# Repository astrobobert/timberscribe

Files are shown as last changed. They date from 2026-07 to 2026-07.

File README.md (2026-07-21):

# TimberScribe — Laser Print Head Server

**TimberScribe** is the scribing side of the **Timber Frame Suite** — an open-source
CAD/CAM system for traditional timber framers. A self-propelled laser print head
rides the timber and burns the joinery layout — mortise outlines, cut lines, bore
centers, labels — directly onto the wood. The joints themselves are still cut by
hand with traditional tools: the laser replaces tape-measure layout, not
craftsmanship.

This repository is the web server that drives the print head. It runs on a
shop server — a plugged-in Raspberry Pi or any laptop on the same network as
the sled — accepts `.tsj` job files from the framer's phone, shows a face
preview dialog, and streams g-code over WiFi to the sled's GRBL controller
(an MKS DLC32 V2.2 running
[FluidNC](https://github.com/bdring/FluidNC); nothing rides the sled but the
controller itself). It also exports `.gcode` files for running from the
controller's SD card when there's no server around — see "Two ways to run a
burn" below.

`.tsj` jobs are produced by the [TimberDraw](https://github.com/astrobobert/timberdraw)
AutoCAD plugin's scribe export (`TScribe` / `TScribeAll`) — one file per timber face,
with profile linework, cut-to-length lines, depth/bevel labels, and peg bores.
The file format is specified in [TSJ_SPEC.md](TSJ_SPEC.md); `app/tsj_parser.py`
is its reference validator. Building the sled itself — printed parts, BOM,
assembly — is covered in [HARDWARE.md](HARDWARE.md).

---

## Two ways to run a burn

**Shop mode (streamed):** the sled joins the shop WiFi (FluidNC station
mode), this server runs on a machine on the same network — a plugged-in
Raspberry Pi (below) or any laptop — and your phone drives the web UI:
upload, preview, adjust, print. G-code streams live to the controller
at `fluidnc.local` (TCP 23), with per-entity status on the phone.

**Field mode (SD card):** out of router range the sled automatically
falls back to broadcasting its own hotspot, and no server is needed at
all. Export a `.gcode` file ahead of time — the **Export .gcode**
button on the face page, or `python export_gcode.py <file.tsj>` — get
it onto your phone, join the sled's hotspot, upload the file to the
controller's SD card through the board's own web page, and run it from
there. A card-run burn doesn't need WiFi once started. (The card:
4–16 GB, FAT32.)

Firmware flashing, WiFi setup, and homing are covered in
[HARDWARE.md](HARDWARE.md) §4. A bench fallback over USB serial also
exists: set `GRBL_TRANSPORT = "serial"` and `SERIAL_PORT` in
`config.py` and plug the DLC32 into USB.

## Setup (any server machine)

```bash
cd TimberScribe
python -m venv .venv
source .venv/bin/activate      # Windows: .venv\Scripts\activate
pip install -r requirements.txt
python run.py
```

Open on a phone on the same network:
```
http://<server-ip>:5000
```

## Shop server on a Raspberry Pi

A Pi plugged in on the shop network makes the server an appliance — no
laptop in the workflow. One-time setup on the Pi:

```bash
git clone https://github.com/astrobobert/timberscribe.git ~/TimberScribe
cd ~/TimberScribe
python -m venv .venv
.venv/bin/pip install -r requirements.txt

# Start on every boot:
sed "s|USER|$(whoami)|g" deploy/timberscribe.service | \
  sudo tee /etc/systemd/system/timberscribe.service
sudo systemctl enable --now timberscribe
```

Then browse to `http://<pi-ip>:5000` from the phone — give the Pi a
reserved address in the router and bookmark it. `fluidnc.local`
resolution works out of the box on Raspberry Pi OS (avahi). Logs:
`journalctl -u timberscribe -f`.

---

## Development

Run with auto-reload:
```bash
flask --app run:app run --debug --host 0.0.0.0 --port 5000
```

The hardware layer (`hardware/executor.py`) gracefully falls back to a
simulation mode when the GRBL controller is unreachable (no sled hotspot,
no serial port), so the full web UI works on a dev machine without the
sled. Simulated completions are labeled as such in the job status.

---

## Project layout

```
TimberScribe/
├── app/
│   ├── __init__.py       Flask app factory
│   ├── routes.py         HTTP endpoints
│   ├── job_store.py      SQLite job queue
│   ├── tsj_parser.py     .tsj file validation and parsing
│   └── executor.py       Background print thread
├── hardware/
│   ├── __init__.py
│   ├── executor.py       GRBL g-code sender (WiFi / USB serial)
│   └── fluidnc/
│       ├── config.yaml   The controller's FluidNC config (source of truth)
│       └── upload_config.py  Bench tool: push config.yaml to the board over USB
├── static/
│   └── style.css         Mobile-friendly stylesheet
├── templates/
│   ├── base.html         Shared layout + status polling
│   ├── index.html        Job list + upload form
│   └── face_select.html  4-face radio dialog with SVG previews
├── data/
│   └── jobs.db           SQLite database (auto-created)
├── uploads/              Uploaded .tsj files
├── config.py             All settings (network, transport, burn defaults)
├── run.py                Entry point
└── requirements.txt
```

---

## API endpoints

| Method | URL | Description |
|---|---|---|
| GET | `/` | Job list + upload form |
| POST | `/upload` | Receive .tsj file |
| GET | `/job/<id>` | Face selector dialog |
| POST | `/job/<id>/select` | Save face selection + settings |
| POST | `/job/<id>/print` | Queue for printing |
| GET | `/job/<id>/delete` | Delete job |
| GET | `/status` | Current print status (JSON) |
| GET | `/status/<id>` | Specific job status (JSON) |

---

## Architecture

The laptop is the server; the DLC32 is the motion controller *and* the
WiFi access point. Everything joins the sled's hotspot:

```
phone (browser) ──┐
                  │  sled's WiFi hotspot (FluidNC AP mode)
                  ▼
   shop laptop — this Flask server
                  │  raw g-code over TCP :23 (FluidNC telnet)
                  ▼
        MKS DLC32 V2.2 (FluidNC)
                  │
   ┌──────────────┼───────────────────┐
   ▼              ▼                   ▼
gantry stepper   bridge drive       laser PWM
(cross axis,     stepper (along     (1.6 W Creality)
carries laser)   the timber)      + 4 limit switches
```

Transport, host, and port live in `config.py` (`GRBL_TRANSPORT`,
`GRBL_HOST`, `GRBL_TCP_PORT`); USB serial remains as a bench fallback.
Earlier iterations used a 3018 Woodpecker GRBL board, then a DLC32 fed
g-code over USB by a Raspberry Pi riding the sled — the DLC32 V2.2's
onboard WiFi retired the Pi. The DLC32 port map (steppers, limit
switches, laser PWM, power in) is still TBD — see
[HARDWARE.md](HARDWARE.md) §4.

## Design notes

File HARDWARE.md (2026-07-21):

# TimberScribe Sled — Hardware Build Guide (Draft v0.1)

The sled is the self-propelled print head: a V-slot frame riding the timber on
nylon rollers, a gantry carrying a 1.6 W laser module, driven by an MKS DLC32
V2.2 controller from a Kobalt 24 V tool battery. The controller hosts its own
WiFi hotspot and takes g-code over it — there is no computer on the sled. This
guide covers printing the brackets, buying the rest, and putting it together.

> **Figure H-1 — The sled assembly (CAD render).**
>
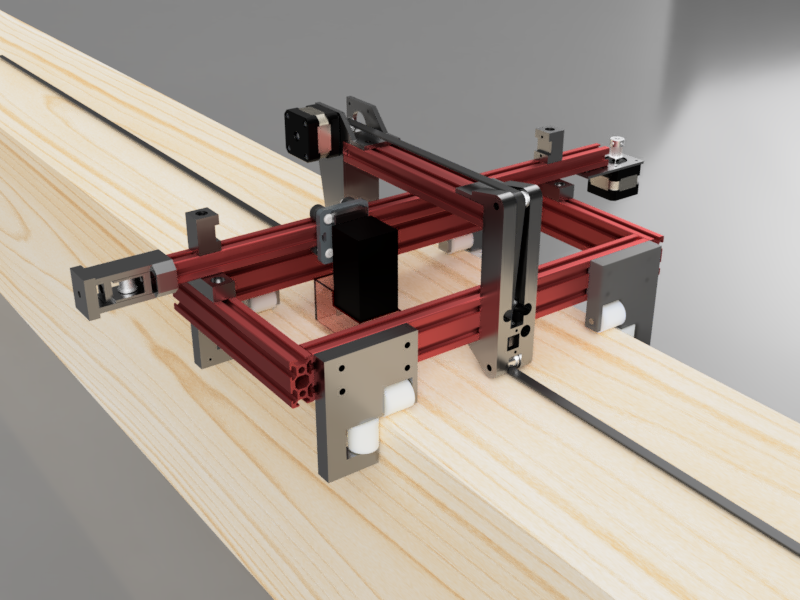
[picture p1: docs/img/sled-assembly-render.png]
Sled assembly render — three-quarter view showing the frame rails, gantry, laser module, and rollers
> 
>
> *Render from `Frame.f3d`; controller and battery not shown. To be replaced
> by a photo of the sled on a squared timber with callouts on: frame rails,
> gantry, laser module, controller, battery, rollers.*

**Status: draft.** Rows marked *TBD* / *verify* need real values from the
bench. Photos land in `docs/img/`.

---

## 1. Printed parts

`3dmodels/` holds the printable parts. Convention: **`.stl` is the
print-ready truth; `.f3d`/`.f3z` is the editable Fusion 360 source** — edit
the source, re-export the STL, commit both.

| Print (`.stl`) | Qty | Source (`.f3d`) | Notes |
|---|---|---|---|
| Bridge Support | 1 | Bridge Supports.f3d | Carries a limit switch |
| Bridge Motor Support | 1 | Bridge Supports.f3d | Two prints share one source file; carries a limit switch |
| Fixed Roller Bracket A | 1 | Fixed Roller Bracket A.f3d | |
| Fixed Roller Bracket B | 1 | Fixed Roller Bracket B.f3d | |
| Float Roller Bracket AA | 1 | Float Roller Bracket A.f3d | AA/AB from one source |
| Float Roller Bracket AB | 1 | Float Roller Bracket A.f3d | |
| Float Roller Bracket BA | 1 | Float Roller Bracket B.f3d | |
| Float Roller Bracket BB | 1 | Float Roller Bracket B.f3d | |
| Gantry to Frame Bracket | 2 | Gantry to Frame Bracket.f3d | |
| Gantry Limit Switch Bracket | 2 | Gantry Limit Switch Bracket.f3d | |
| Laser Mount | 1 | Laser Mount.f3d | |
| MKS DLC32 Bracket | 1 | MKS DLC32 Bracket.f3z | The controller mount |
| Tensioner_Body1 | 1 | Tensioner.f3z | Belt tensioner, piece 1 of 3 |
| Tensioner_Body2 | 1 | Tensioner.f3z | Belt tensioner, piece 2 of 3 |
| Tensioner_Body3 | 1 | Tensioner.f3z | Belt tensioner, piece 3 of 3 |

`Frame.f3d` is the **sled assembly file** — the whole machine modeled
together. It is not a printed part and has no STL.

Print settings *(fill in what has worked)*: material ______ , layer ______ ,
infill ______ , supports ______ .

**Still to be designed:**

| Part | Qty | Notes |
|---|---|---|
| Battery Mount | 1 | Kobalt pack cradle |
| Cable Clips | 2+ | |

## 2. Bill of materials

### 2.1 Frame

| Qty | Part | Status |
|---|---|---|
| 2 | V-Slot 20×40 × 400 mm | ✓ |
| 3 | V-Slot 20×40 × 200 mm | ✓ |

### 2.2 Motion system

| Qty | Part | Status |
|---|---|---|
| 1 | 42BL4002-24A stepper motor | ✓ |
| 1 | GT2 10 mm motor pulleys, 20T, 6 mm bore | ✓ |
| 1 | GT2 10 mm idler pulleys, toothed | ✓ |
| 2 | GT2 10 mm idler pulleys, smooth | ✓ |
| 1 | GT2 10 mm belt (open, by the meter) | cut to suit — length set by the timber to be scribed |
| 1 | Belt tensioner | printed — 3-piece, §1 |
| 1 | Gantry: [V-Slot NEMA 17 belt-driven linear actuator bundle](https://www.ebay.com/itm/405009993772?var=675070040219) (prebuilt) | ✓ — stock tensioner swapped for the printed one (§1) |
| 8 | 25×25 mm nylon V-rollers (uxcell; 686Z roller bearings, 6 mm bore) | ✓ |
| 8 | 5.9 mm axle rods | slip fit through the 6 mm bearing bore |

### 2.3 Electronics

| Qty | Part | Status |
|---|---|---|
| 1 | MKS DLC32 V2.2 controller | ✓ — flashed with FluidNC (§4.1); hosts the sled's WiFi hotspot |
| 2 | Stepper driver sticks — TMC2209 | **the DLC32's driver sockets are plug-in** (manual §VI) — without a stick the motor connector is dead. Per-socket red DIP switch (M0/M1/M2, up=ON=High): **1 ON, 2 ON, 3 down = 1/16 for TMC2209**. Orientation: stick's EN pin → socket EN (top of green column), DIR → DIR (bottom); check both corners — 180° reversed = burnt stick. Vref (volts) ≈ motor rated amps (≈70% run current); never insert/remove powered |
| 1 | Creality CV 1.6 W laser module | ✓ |
| 4 | Limit switches — 3-wire modules labeled IN/GND/12V, pre-mated connectors | 2 on the gantry brackets, 2 on the bridge supports; run fine from the endstop header's 5 V supply (verified 2026-07-18: `Pn:X`/`Pn:Y` respond, polarity matches the config's `:low`) |
| 2 | Stepper motor extension cables | TBD |
| 1 | Controller mount | printed — MKS DLC32 Bracket, §1 |
| 1 | Wiring harness | TBD |

### 2.4 Power

| Qty | Part | Status |
|---|---|---|
| 1 | Kobalt 24 V battery | ✓ |
| 1 | Kobalt battery adapter | need source |
| 1 | 24 V voltage regulator | need exact model — *verify whether still required: with the Pi gone there is no 5 V load, and the DLC32 accepts 12–24 V DC directly* |
| 1 | Main fuse | rating TBD |
| 1 | Master power switch | TBD |
| 1 | Emergency stop | recommended |

### 2.5 Laser accessories

| Qty | Part | Status |
|---|---|---|
| 1 | Air assist pump | recommended |
| 1 | Air nozzle | TBD |
| 1 | Air tubing | TBD |

### 2.6 Fasteners & sundries *(the usually-missing 50–100 pieces — tally during the next assembly)*

| Qty | Part |
|---|---|
| __ | M5 T-nuts |
| __ | M5×8 socket head screws |
| __ | M5×10 socket head screws |
| __ | M5×16 socket head screws |
| __ | M3 screws |
| __ | M3 locknuts |
| __ | Spacers / washers |
| __ | Heat-set inserts (if applicable) |
| __ | Zip ties, spiral wrap / braided sleeve |

## 3. Assembly

Photo-led, one subassembly per step — shoot these during the next
build/teardown.

1. **Frame** — V-slot layout and joining.
   > *[photo: bare frame, rail lengths labeled.]*
2. **Rollers** — fixed brackets one side, floating brackets the other; how
   the float preloads against timber width variation.
   > *[photo: roller bracket pair on a rail edge, fixed vs float called out.]*
3. **Gantry** — the cross-timber axis; it carries the laser. Arrives as a
   prebuilt belt-driven actuator (§2.2): swap its stock tensioner for the
   printed 3-piece one, then mount via the gantry-to-frame brackets.
   > *[photo: gantry assembled, belt path visible, printed tensioner called
   > out.]*
4. **Bridge** — the along-the-timber drive axis, separate from the gantry:
   the bridge support and bridge motor support carry the drive stepper and
   route the timing belt up and over the laser so the belt can clear it.
   > *[photo: bridge mounted, belt path over the laser visible.]*
5. **Laser mount** — module on the mount, air assist routing.
   > *[photo: laser mount close-up.]*
6. **Electronics + power** — DLC32 in its bracket, limit switches, battery,
   regulator, fusing, e-stop, harness routing.
   > *[photo: electronics bay, labeled.]*

## 4. Wiring

> *[photo: harness overview + a wiring diagram when the design settles.]*

Port map (from `hardware/fluidnc/config.yaml`, confirmed on the board
2026-07-18):

| Sled function | DLC32 header | Firmware pin |
|---|---|---|
| Bridge drive stepper (X — along the timber) | X motor header | step I2SO.1, dir I2SO.2 (via the board's shift register) |
| Gantry stepper (Y — across the timber) | Y motor header | step I2SO.5, dir I2SO.6 |
| X limit switch | X− header | gpio.36, active low |
| Y limit switch | Y− header | gpio.35, active low |
| Laser (TTL PWM) | laser header | gpio.32, 5 kHz |
| Power in | 12–24 V DC screw terminal | — |
| Z header | unused | no Z axis — the laser is fixed-focus |

**Homing** (configured in `config.yaml`, matches the `.tsj` coordinate
frame): `$H` homes Y first — gantry toward the **fixed-roller (datum)
edge** — then X — bridge toward the **anchor (tape-hook) end**. Each
axis runs to its switch, backs off 2 mm, and calls that spot zero, so
machine coordinates measure exactly like the `.tsj` file. Homing wiring
for now: **one switch per axis at the homing end** (the datum-side
gantry switch → Y− header, the anchor-end bridge switch → X− header).
The switches are 3-wire modules on pre-mated connectors; the board's
endstop headers are **5 V / GND / S** (manual §IX) — match the S/G/V
markings on the switch PCB to the board silkscreen before powering, and
if the board's 5 V LED goes dark at power-up, unplug immediately: the
manual calls that a short in the endstop wiring. The far-end switches
stay unwired until
we opt into series-NC wiring (which flips the inputs to active-high and
enables `hard_limits`) — the sled carries 4 switches but the board has
one limit input per axis. Homing speeds are detuned for first tests
(seek 2000 mm/min); raise them once trusted. Steps/mm and travel values
are donor values (100 steps/mm assumes 16 T pulleys; the BOM has 20 T,
which at 16 microsteps works out to 80) — calibrate when the motors are
wired.

> **Note:** the server ([README](README.md), `hardware/executor.py`,
> `config.py`) speaks g-code to the DLC32 **over WiFi** — the controller
> hosts its own hotspot (FluidNC AP mode) and takes raw g-code on TCP
> port 23; the laptop running the server just joins the sled's network.
> Lineage: a 3018 Woodpecker (GRBL) board ran the first bench prototype;
> then a DLC32 V2.1 fed over USB serial by a Raspberry Pi 5 riding the
> sled; the DLC32 V2.2's onboard WiFi retired the Pi — nothing rides the
> sled now but the controller. USB serial to the DLC32 remains as a
> bench fallback (`GRBL_TRANSPORT = "serial"` in `config.py`).

### 4.1 Firmware — FluidNC

The V2.2 board runs [FluidNC](https://github.com/bdring/FluidNC) (the
maintained successor to Grbl_ESP32) in place of the stock MKS firmware.
The controller's configuration is version-controlled at
`hardware/fluidnc/config.yaml` — edit it there and push it to the board
over USB with `hardware/fluidnc/upload_config.py`, which also prints
the boot log so config errors are visible immediately.

Bench state as of 2026-07-18:

| Item | Value | Status |
|---|---|---|
| Firmware | FluidNC v4.0.3 (esp32-wifi build), flashed via the [web installer](https://installer.fluidnc.com) | ✓ confirmed on the board |
| Config | `hardware/fluidnc/config.yaml` — base: official `MKS_DLC32_v21_laser.yaml`; Z axis removed (its floating limit input, gpio.34, threw a phantom hard-limit alarm every boot) | ✓ uploaded, boots clean |
| WiFi mode | AP (hotspot) — SSID **FluidNC**, password **12345678** (FluidNC defaults), address `192.168.4.1` — moved off the default `192.168.0.1`, which collided with the shop LAN (`$AP/IP=192.168.4.1`, stored on the board, **not** in config.yaml); matches `config.py` `GRBL_AP_SSID` / `GRBL_HOST` | ✓ boot log |
| G-code port | TCP 23 — "Telnet started on port 23" | ✓ boot log |
| Protocol | TimberScribe preamble `G20`/`G90`/`M5` acknowledged, status Idle | ✓ over USB |
| Spindle | **Laser** on gpio.32 at 5 kHz. Burns use **M4 dynamic power**: the beam scales with actual speed and turns off at standstill, so streaming pauses and dropped links fail dark, never parked-and-firing | ✓ in config; **bench check owed once wired: beam dark whenever motion stops** |
| S-value scale | laser `speed_map` tops at 1000 = `config.py GRBL_SPINDLE_MAX_S` | ✓ |
| Homing | Y (gantry → datum edge) then X (bridge → anchor end), zero at the switch + 2 mm pulloff, detuned speeds | ✓ in config; **test owed once switches are wired** (§4) |
| Steps/mm, travels | donor values in the config | calibrate at wiring (§4 port map) |

The board's own FluidNC web page (`http://192.168.4.1` on the hotspot,
`http://fluidnc.local` on the shop LAN) is also the **jog and home
surface** (touch-friendly — drive it from the phone), and can upload a
g-code file to the SD card and run it from there — the field workflow:
export with TimberScribe's **Export .gcode** button (or
`export_gcode.py`), upload from the phone, run from the card. A card
run keeps burning even if WiFi drops mid-job. Card: 4–16 GB, FAT32
(manual §IV).

## 5. Safety

- 1.6 W diode laser: **wear the OD-rated goggles for 445 nm — always.** No
  eyes at timber level during a burn; the beam scatters off wood.
- Never leave a burn unattended; char can smolder. Keep water or an
  extinguisher at the sawhorses.
- Air assist reduces flare-ups and cleans the cut — treat it as standard
  equipment, not optional.
- E-stop within reach once fitted; until then, the master switch is the stop.

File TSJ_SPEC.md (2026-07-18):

# TSJ_SPEC — The TimberScribe Job Format, v2.0

A `.tsj` file describes the laser burn job for **one face of one timber**: the
linework to scribe, the machine settings to scribe it with, and a preview for
the operator. It is plain **JSON**, `snake_case` keys, all dimensions in
**inches**, encoded **UTF-8 without BOM** (the parser rejects a BOM).

This document is the canonical spec. The reference implementations are:

- **Producer:** `ScribeTsj.cs` in the
  [timberdraw](https://github.com/astrobobert/timberdraw) repo
  (`Managed/ScribeTsj.cs`) — the active writer. The legacy TimberTag
  `TsjWriter` produced the same schema; files from either burn identically.
- **Consumer:** `app/tsj_parser.py` in this repo (validation) and
  `hardware/executor.py` (the burn loop).

**Any schema change must touch the writer AND the parser in the same change.**

---

## File naming

One file per side face, named `<stem>_faceN.tsj` with `N` = 1–4:

- Principal timbers: the stem is the sanitized location label —
  `P-2A_face1.tsj`.
- Repetitive families (braces, joists, commons, purlins) export one set per
  unique geometry: `<Family>_<W>x<D>[_xCOUNT]_faceN.tsj` —
  `Brace_4x5_x12_face1.tsj` means *cut twelve of these*.
- Spaces and filesystem-invalid characters are replaced with `_`.

Only faces that carry marks are written; a timber may ship fewer than 4 files.

## Coordinate system

Per face, as the laser sees the timber:

- **Origin** — the face's **upper-left corner**: the datum edge (reference
  arris) at the anchor end.
- **X** — along the timber's length; anchor end = 0, increasing toward the
  far end.
- **Y** — across the face, **downward** (toward the framer); datum edge = 0.
- **Units** — inches, decimal.
- **Angles** — degrees. Arc sweeps run counter-clockwise from `start_angle_deg`
  to `end_angle_deg` *in this y-down frame*.

The face numbering (RS1–RS4) and datum-first shop practice are described in
the TimberDraw user guide (ch. 13); this file only fixes the geometry
contract.

## Top-level structure

```json
{
  "tsj_version": "2.0",
  "generated":   "2026-07-04T18:20:00.0000000Z",
  "timber":      { ... },
  "face":        { ... },
  "settings":    { ... },
  "entities":    [ ... ],
  "preview_svg": "<svg ...>...</svg>"
}
```

| Field | Type | Required | Notes |
|---|---|---|---|
| `tsj_version` | string | yes | `"2.0"`. The parser accepts any `2.x`. |
| `generated` | string | no | ISO-8601 UTC timestamp of export. |
| `timber` | object | yes | Identity + overall dimensions (below). |
| `face` | object | yes | Which face and its extents (below). |
| `settings` | object | no | Machine profiles; consumer defaults apply if absent. |
| `entities` | array | yes (may be empty) | The burn geometry (below). |
| `preview_svg` | string | no | Inline SVG for the face-selector UI; a placeholder is synthesized if absent. |

Optional/null fields are **omitted** by the writer, not emitted as `null`.

### `timber`

| Field | Type | Required | Notes |
|---|---|---|---|
| `id` | string | yes, non-empty | The timber's location label (or family stem for repeats). |
| `description` | string | no | Free text shown in the job list. |
| `length_in` | number > 0 | yes | Overall length. |
| `width_in` | number > 0 | yes | Section width. |
| `height_in` | number | no | Section depth. |
| `species` | string | no | Reserved; not currently written. |

### `face`

| Field | Type | Required | Notes |
|---|---|---|---|
| `number` | int 1–4 | yes | RS face number. The parser rejects anything else. |
| `length_in` | number > 0 | yes | Face extent in X. |
| `width_in` | number > 0 | yes | Face extent in Y. |
| `origin`, `x_axis`, `y_axis` | string | no | Human-readable descriptions of the coordinate frame. **Informative only** — consumers must not parse them. |

### `settings`

Two machine profiles. All values are operator-adjustable in the server UI
before printing; the file's values are starting points.

```json
"settings": {
  "scribe": { "feed_in_per_min": 32,  "laser_power_pct": 70, "passes": 1 },
  "travel": { "feed_in_per_min": 118, "laser_power_pct": 0 }
}
```

| Field | Default | Meaning |
|---|---|---|
| `scribe.feed_in_per_min` | 32 | Head speed while burning. |
| `scribe.laser_power_pct` | 70 | Laser power while burning, 0–100. |
| `scribe.passes` | 1 | Repeat count per entity. |
| `travel.feed_in_per_min` | 118 | Head speed between entities, laser off. |
| `travel.laser_power_pct` | 0 | Must be 0. |
| `*.description` | — | Informative only. |

## Entities

Each entity is one burnable mark. `type` is required; the burn loop **skips
unknown types with a log line** (forward compatibility — additive types don't
break old firmware).

Only *burnable* geometry appears here. Text (labels, depths, bevels, the
blind-peg `B`) is pre-stroked by the producer into `line`/`polyline` entities
— **the format has no text entity** and consumers need no fonts. Hidden /
boundary linework appears only in the preview SVG, never in `entities`.

### `line`

```json
{ "type": "line", "start": [x, y], "end": [x, y] }
```

### `polyline`

```json
{ "type": "polyline", "closed": true, "points": [[x, y], [x, y], ...] }
```

When `closed` is true, the burner returns to `points[0]` after the last point;
the closing point is **not** repeated in `points`.

### `circle`

```json
{ "type": "circle", "center": [x, y], "radius_in": 0.5, "scribe_center": true }
```

Peg bores. With `scribe_center` true the burner marks a center cross first,
then traces the outline — the framer drills to the cross.

### `arc`

```json
{ "type": "arc", "center": [x, y], "radius_in": 2.0,
  "start_angle_deg": 0, "end_angle_deg": 90 }
```

Sweep is counter-clockwise from start to end angle in the face's y-down frame.

## `preview_svg`

A complete inline `<svg>` document, `viewBox` in face inches, rendered by the
face-selector UI. It shows more than the burn set, styled so cut-vs-context
reads at a glance (colorblind-safe — no green):

- **Burned cut lines** — solid black, heavier stroke.
- **Stock boundary** (face outline, not burned) — solid gray.
- **Preview-only marks** (hidden linework) — dashed blue.
- **Anchor marker** — an orange circle-and-cross at the origin.

Consumers must treat the SVG as opaque display content; the burn truth is
`entities` only.

## Validation contract

What `app/tsj_parser.py` enforces (`TsjError`, job rejected):

- File readable, valid JSON, **no BOM**.
- `tsj_version` starts with `2.`.
- `timber` present; `timber.id` non-empty; `timber.length_in` / `width_in`
  positive numbers.
- `face` present; `face.number` in 1–4; `face.length_in` / `width_in`
  positive numbers.
- `entities` is a list; every entity has a `type`.

Warning only (job accepted, logged):

- Any coordinate outside the face bounds by more than **0.5"** — usually a
  projection bug in the producer; the operator sees it in the log.

Missing `settings` fall back to the defaults above. A missing `preview_svg`
gets a gray "No preview" placeholder.

## Minimal example

A 10' × 8" face with one cut-to-length line, a mortise outline, and a peg
bore:

```json
{
  "tsj_version": "2.0",
  "generated": "2026-07-04T18:20:00.0000000Z",
  "timber": { "id": "TG-2", "length_in": 120.0, "width_in": 8.0, "height_in": 10.0 },
  "face":   { "number": 1, "length_in": 120.0, "width_in": 8.0 },
  "settings": {
    "scribe": { "feed_in_per_min": 32, "laser_power_pct": 70, "passes": 1 },
    "travel": { "feed_in_per_min": 118, "laser_power_pct": 0 }
  },
  "entities": [
    { "type": "line", "start": [4.0, 0.0], "end": [4.0, 8.0] },
    { "type": "polyline", "closed": true,
      "points": [[56.0, 3.0], [64.0, 3.0], [64.0, 5.0], [56.0, 5.0]] },
    { "type": "circle", "center": [60.0, 4.0], "radius_in": 0.5, "scribe_center": true }
  ],
  "preview_svg": "<svg viewBox=\"0 0 120.000 8.000\" xmlns=\"http://www.w3.org/2000/svg\">...</svg>"
}
```

## Version history

- **2.0** — current. Introduced by TimberTag's `TsjWriter`; TimberDraw's
  managed exporter (`Managed/ScribeTsj.cs`) writes the identical schema.
  Consumers should accept any `2.x` and skip unknown entity types; producers
  bumping the minor version must stay additive.

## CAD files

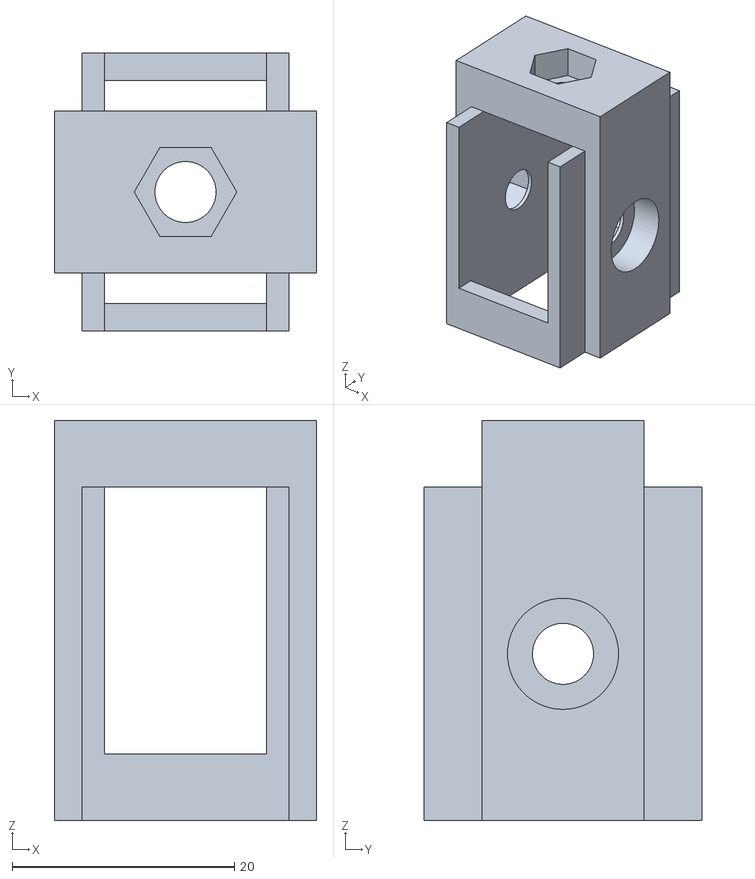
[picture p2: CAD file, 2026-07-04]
3dmodels/Tensioner_Body3.stl
23.6 x 25.0 x 36.0

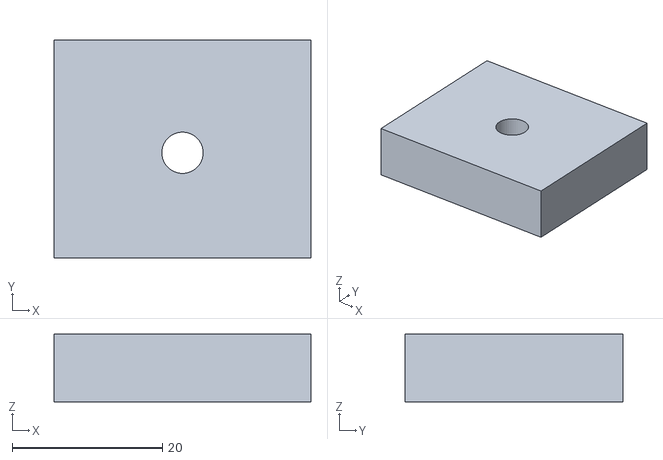
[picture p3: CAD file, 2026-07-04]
3dmodels/Tensioner_Body2.stl
34.2 x 29.0 x 9.00

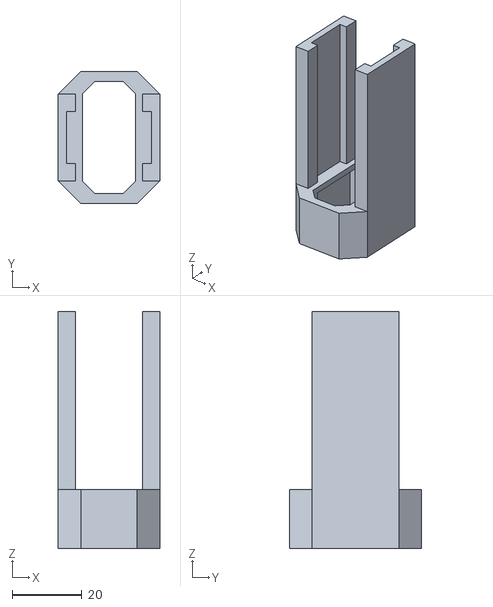
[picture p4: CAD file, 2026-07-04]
3dmodels/Tensioner_Body1.stl
29.2 x 38.0 x 68.0

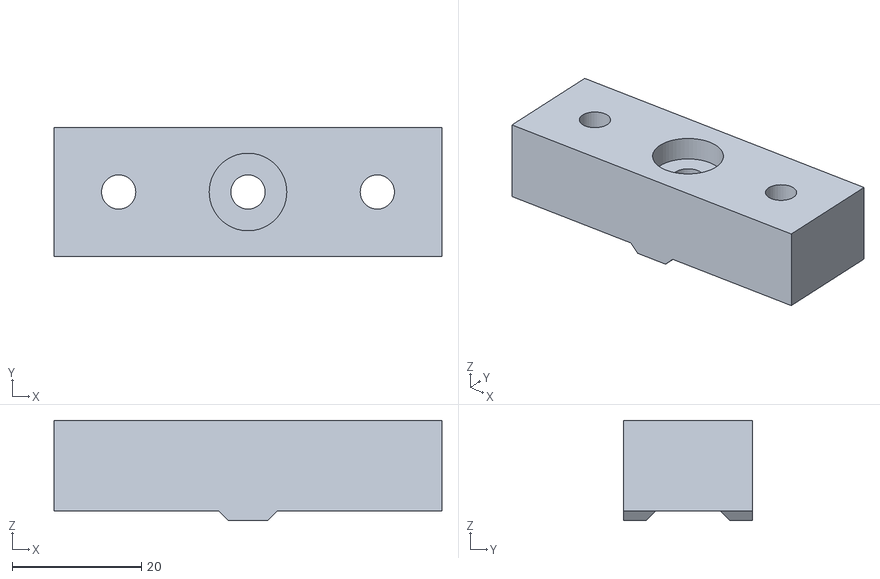
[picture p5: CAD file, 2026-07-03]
3dmodels/Gantry to Frame Bracket.stl
60.0 x 20.0 x 15.5

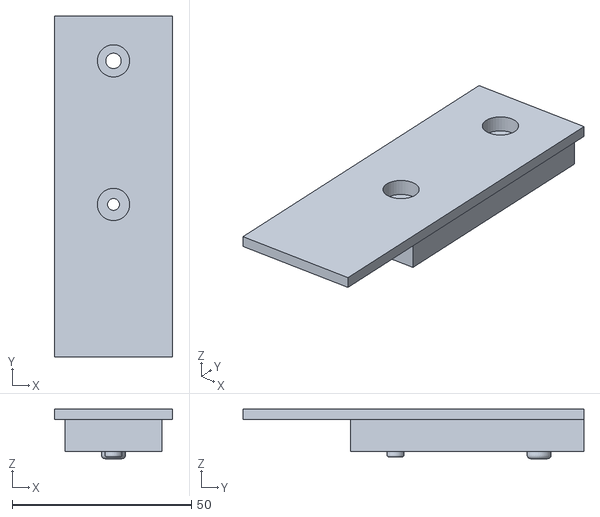
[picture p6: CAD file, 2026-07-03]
3dmodels/Laser Mount.stl
33.0 x 95.0 x 13.8

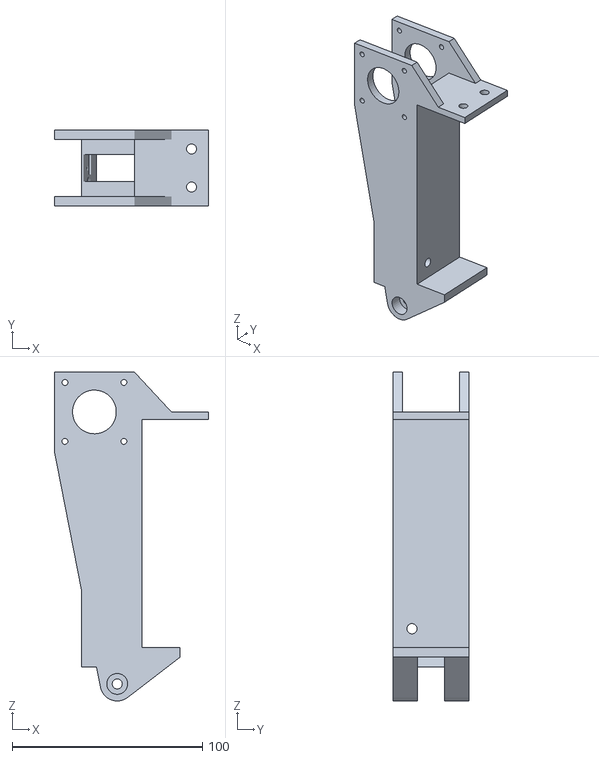
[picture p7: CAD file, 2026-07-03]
3dmodels/Bridge Motor Support.stl
81.0 x 40.0 x 173.0

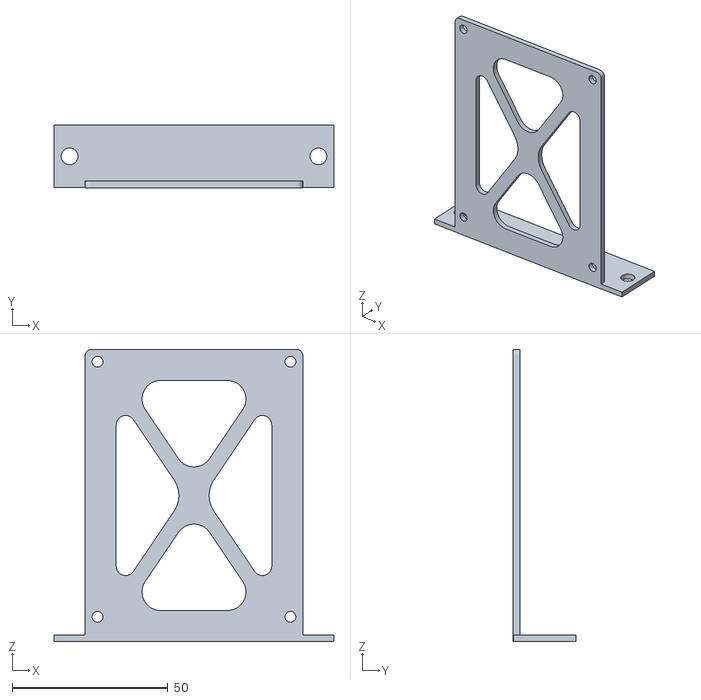
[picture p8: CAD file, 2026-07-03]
3dmodels/MKS DLC32 Bracket.stl
90.0 x 20.1 x 94.0

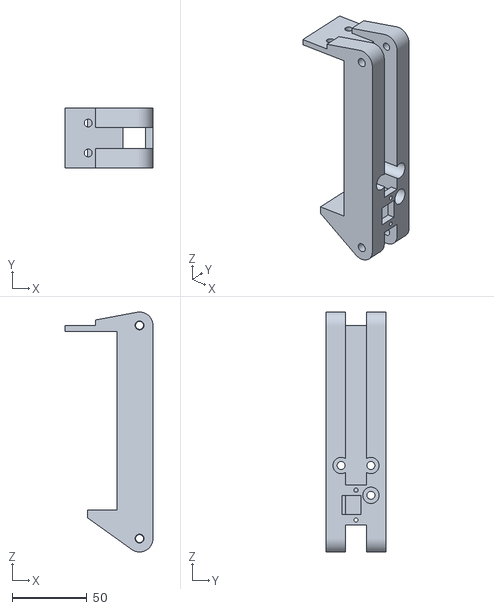
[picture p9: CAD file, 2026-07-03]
3dmodels/Bridge Support.stl
59.0 x 40.0 x 161.0

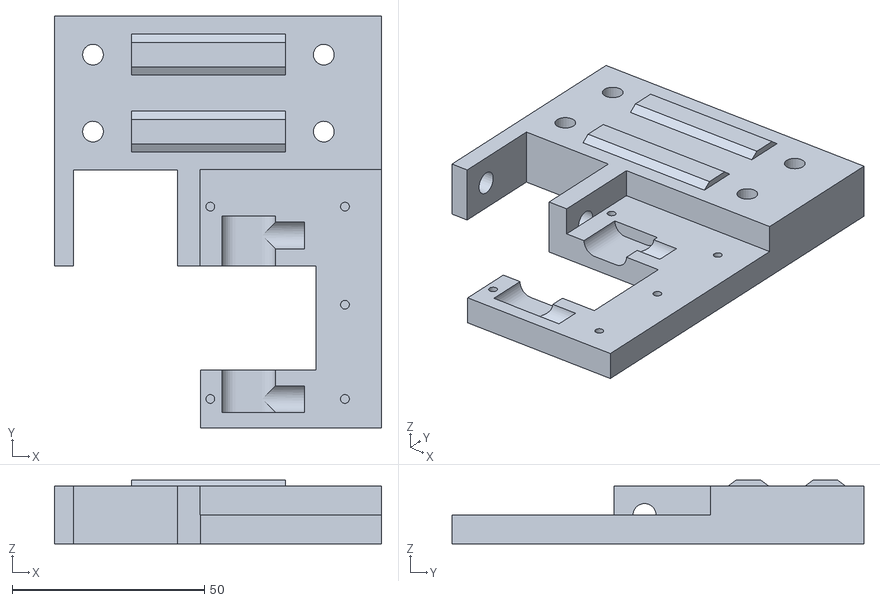
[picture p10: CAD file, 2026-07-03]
3dmodels/Float Roller Bracket BA.stl
85.0 x 107.0 x 16.6

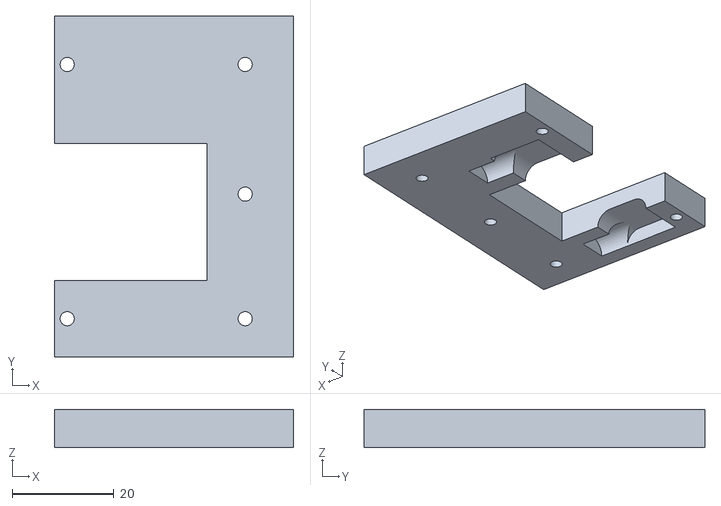
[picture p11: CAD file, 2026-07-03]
3dmodels/Float Roller Bracket BB.stl
47.0 x 67.0 x 7.50

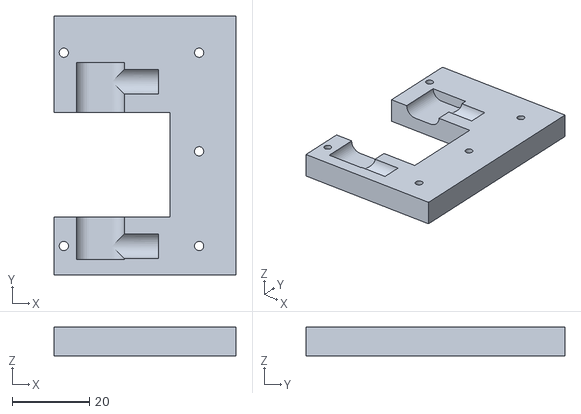
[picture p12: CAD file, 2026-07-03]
3dmodels/Float Roller Bracket AB.stl
47.0 x 67.0 x 7.50

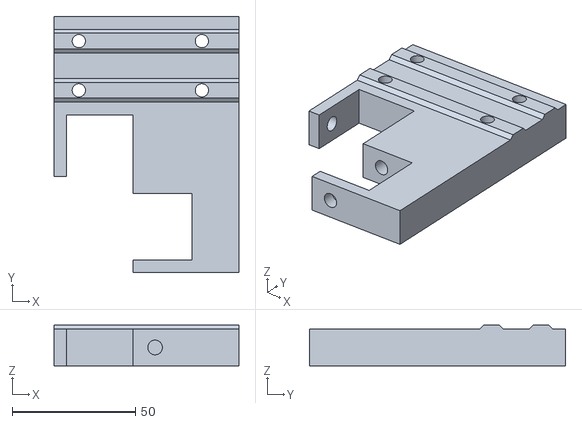
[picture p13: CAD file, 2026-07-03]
3dmodels/Fixed Roller Bracket A.stl
75.0 x 104.0 x 16.6

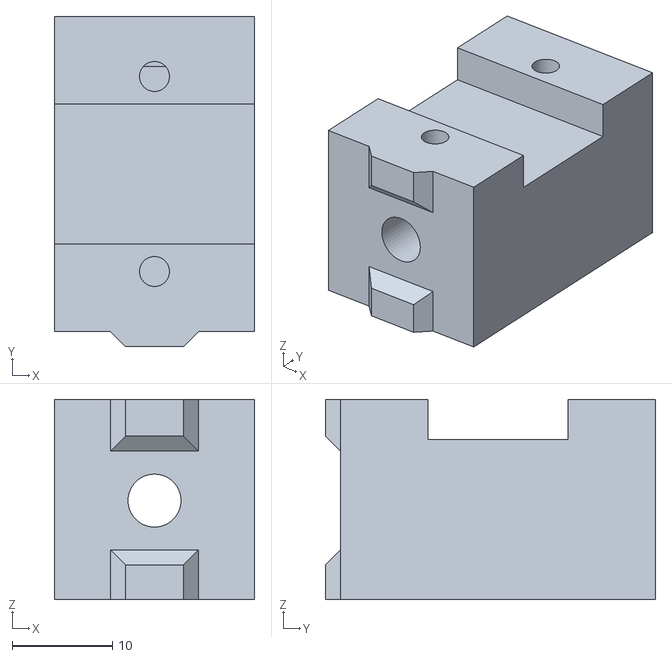
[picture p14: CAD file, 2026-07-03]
3dmodels/Gantry Limit Switch Bracket.stl
20.0 x 33.0 x 20.0

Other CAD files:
3dmodels/Float Roller Bracket AA.stl
3dmodels/Fixed Roller Bracket B.stl
3dmodels/Bridge Supports.f3d
3dmodels/Fixed Roller Bracket A.f3d
3dmodels/Fixed Roller Bracket B.f3d
3dmodels/Float Roller Bracket A.f3d
3dmodels/Float Roller Bracket B.f3d
3dmodels/Frame.f3d
3dmodels/Gantry Limit Switch Bracket.f3d
3dmodels/Gantry to Frame Bracket.f3d
3dmodels/Laser Mount.f3d
3dmodels/Tensioner.f3z

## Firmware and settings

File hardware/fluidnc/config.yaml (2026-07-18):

# Basic configuration file for X/Y Laser using GT2 belts 1.8ºNEMA motors
# at 16 microSteps and 16 Tooth pulleys

board: MKS-DLC32 V2.2
name: TimberScribe Sled
meta: base official MKS_DLC32_v21_laser.yaml; TimberScribe sled 2026-07-18

kinematics:
  Cartesian:

stepping:
  engine: I2S_STATIC
  idle_ms: 255
  pulse_us: 4
  dir_delay_us: 1
  disable_delay_us: 0
axes:
  shared_stepper_disable_pin: I2SO.0
  x:
    steps_per_mm: 100
    max_rate_mm_per_min: 16000
    acceleration_mm_per_sec2: 1500
    max_travel_mm: 895
    soft_limits: false
    homing:
      # Bridge homes SECOND (cycle 2), toward the anchor / tape-hook
      # end of the timber — the switch wired to the X- header must be
      # the anchor-end one, so machine X=0 is where .tsj X measures
      # from. Speeds detuned for first tests; raise after calibration.
      cycle: 2
      positive_direction: false
      mpos_mm: 0.000
      feed_mm_per_min: 300.000
      seek_mm_per_min: 2000.000
      settle_ms: 500
      seek_scaler: 1.100
      feed_scaler: 1.100

    motor0:
      limit_neg_pin: gpio.36:low
      hard_limits: false
      pulloff_mm: 2.000
      stepstick:
        step_pin: I2SO.1
        direction_pin: I2SO.2:low

  y:
    steps_per_mm: 100
    max_rate_mm_per_min: 16000
    acceleration_mm_per_sec2: 1500
    max_travel_mm: 880
    soft_limits: false
    homing:
      # Gantry homes FIRST (cycle 1), toward the fixed-roller (datum)
      # edge — the switch wired to the Y- header must be the one on
      # that side, so machine Y=0 is the edge .tsj Y measures from.
      cycle: 1
      positive_direction: false
      mpos_mm: 0.000
      feed_mm_per_min: 300.000
      seek_mm_per_min: 2000.000
      settle_ms: 500
      seek_scaler: 1.100
      feed_scaler: 1.100

    motor0:
      limit_neg_pin: gpio.35:low
      hard_limits: false
      pulloff_mm: 2.000
      stepstick:
        step_pin: I2SO.5
        direction_pin: I2SO.6:high

# No Z axis: the sled is two-axis (X = bridge, along the timber;
# Y = gantry, across it) with a fixed-focus laser. The donor config's
# Z limit (gpio.34, active-high, no internal pulls) floated high with
# nothing wired and threw a phantom hard-limit alarm at every boot.

i2so:
  bck_pin: gpio.16
  data_pin: gpio.21
  ws_pin: gpio.17

spi:
  miso_pin: gpio.12
  mosi_pin: gpio.13
  sck_pin: gpio.14

sdcard:
  cs_pin: gpio.15
  card_detect_pin: NO_PIN
#  card_detect_pin: gpio.39
  
control:
  safety_door_pin: NO_PIN
  reset_pin: NO_PIN
  feed_hold_pin: NO_PIN
  cycle_start_pin: NO_PIN
  macro0_pin: NO_PIN
  macro1_pin: NO_PIN
  macro2_pin: NO_PIN
  macro3_pin: NO_PIN

macros:
  startup_line0:
  startup_line1:
  macro0:
  macro1:
  macro2:
  macro3:

coolant:
  flood_pin: NO_PIN
  mist_pin: NO_PIN
  delay_ms: 0

#probe:
#  pin: gpio.22
#  check_mode_start: true

Laser:
  pwm_hz: 5000
  output_pin: gpio.32
  disable_with_s0: false
  s0_with_disable: false
  tool_num: 0
  speed_map: 0=0.000% 1000=100.000%
#PWM:
#  direction_pin: NO_PIN
#  spinup_ms: 1000
#  spindown_ms: 1000
  
user_outputs:
  analog0_pin: NO_PIN
  analog1_pin: NO_PIN
  analog2_pin: NO_PIN
  analog3_pin: NO_PIN
  analog0_hz: 5000
  analog1_hz: 5000
  analog2_hz: 5000
  analog3_hz: 5000
  #Beeper connector. Command: "M62 P0" turn beeper On. 
  #"G4 P0.5" wait for 0.5s. "M63 P0" turn beeper OFF
  digital0_pin: I2SO.7
  digital1_pin: NO_PIN
  digital2_pin: NO_PIN
  digital3_pin: NO_PIN

start:
  must_home: false


#MKS DLC32 v2.1 pinMap

# X- gpio.36
# SD_DET gpio.39
# Z- gpio.34
# Y- gpio.35
# SPINDLE PWM gpio.32
# LCD_RS gpio.33
# LCD_CS_INV gpio.25
# LCD_TOUCH_CS_INV gpio.26
# LCD_RST_INV gpio.27
# SD_SCK gpio.14
# SD_DO gpio.12
# SD_DI gpio.13
# SD_CS gpio.15
# I2C_SDA gpio.0
# I2C_SCL gpio.4
# I2S_BCK gpio.16
# I2S_WS gpio.17
# LCD_EN_INV gpio.5
# LCD_SCK gpio.18
# LCD_MISO gpio.19
# I2S_DATA gpio.21
# RXD0 gpio.3
# TXD0 gpio.1
# Probe gpio.22
# LCD_MOSI gpio.23

# XYZ_EN I2SO.0
# X_STEP I2SO.1
# X_DIR I2SO.2
# Z_STEP I2SO.3
# Z_DIR I2SO.4
# Y_STEP I2SO.5
# Y_DIR I2SO.6
# BEEPER I2SO.7

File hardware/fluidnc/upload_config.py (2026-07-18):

"""Bench tool — push config.yaml to the DLC32 over USB.

The controller's FluidNC configuration lives in the sibling
``config.yaml`` (source of truth, version-controlled). After editing
it, run this with the board on USB to upload it and restart:

    pip install pyserial xmodem        # once
    python upload_config.py            # default port COM4
    python upload_config.py --port COM7

Nothing else may hold the port open (close the FluidNC web-installer
tab / any serial monitor first). The script sends the file via XModem
($Xmodem/Receive), restarts the board ($Bye), and prints the boot log
— read it: config errors show up there as [MSG:ERR:...] lines, and a
healthy boot ends with the machine name, "AP started", and "Telnet
started on port 23".
"""

import argparse
import os
import sys
import time

import serial
from xmodem import XMODEM


def main():
    ap = argparse.ArgumentParser(description=__doc__.splitlines()[0])
    ap.add_argument("--port", default="COM4", help="serial port (default COM4)")
    ap.add_argument(
        "--file",
        default=os.path.join(os.path.dirname(os.path.abspath(__file__)),
                             "config.yaml"),
        help="config file to upload (default: sibling config.yaml)",
    )
    args = ap.parse_args()

    ser = serial.Serial(args.port, 115200, timeout=2)
    time.sleep(0.3)
    ser.reset_input_buffer()

    def cmd(line, wait=1.0):
        ser.write((line + "\n").encode())
        time.sleep(wait)
        out = ser.read_all().decode(errors="replace")
        print(f">>> {line}\n{out}")
        return out

    # Hand the board the file over XModem-CRC.
    ser.write(b"$Xmodem/Receive=config.yaml\n")
    deadline = time.time() + 10
    while time.time() < deadline:
        b = ser.read(1)
        if b == b"C":          # receiver's CRC poll — ready for data
            break
        if b:
            sys.stdout.write(b.decode(errors="replace"))
    else:
        sys.exit("Board never started XModem — is this a FluidNC board?")

    def getc(size, timeout=1):
        return ser.read(size) or None

    def putc(data, timeout=1):
        return ser.write(data)

    with open(args.file, "rb") as f:
        if not XMODEM(getc, putc).send(f, retry=8):
            sys.exit("XModem transfer failed")
    time.sleep(1.0)
    print(ser.read_all().decode(errors="replace"))
    cmd("$LocalFS/List")

    print("=== restarting — boot log follows ===")
    ser.write(b"$Bye\n")
    time.sleep(6.0)
    print(ser.read_all().decode(errors="replace"))
    cmd("$I", wait=1.5)
    ser.close()


if __name__ == "__main__":
    main()

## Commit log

2026-07-03 Initial commit: TimberScribe split out of the timber-frame-suite monorepo
    Raspberry Pi laser layout head for timber framing. Flask server accepts
    .tsj v2.0 job files (exported by the sibling timberdraw repo), shows a
    4-face SVG preview, and drives the self-propelled print head that burns
    layout marks onto the timber. Includes the printable hardware: STLs plus
    Fusion 360 sources (3dmodels/).
    Full pre-split history lives in the private archive:
    https://github.com/astrobobert/timber-frame-suite-archive
    [Bridge Motor Support.stl, Bridge Support.stl, Bridge Supports.f3d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]
2026-07-04 README: lead with the suite pitch + .tsj provenance
    Open with the craft-forward positioning (open-source CAD/CAM for
    traditional framers; the laser replaces tape-measure layout, not
    craftsmanship) and note that .tsj jobs come from TimberDraw's
    TScribe/TScribeAll export.
2026-07-04 TSJ_SPEC.md: canonical .tsj v2.0 specification
    Sourced from the two reference implementations -- TimberDraw's
    Managed/ScribeTsj.cs (writer) and app/tsj_parser.py (validator) --
    documenting their actual intersection: snake_case JSON, inches, UTF-8
    no-BOM, per-face coordinate frame (upper-left datum origin, y-down),
    the four entity types (unknown types skipped for forward compat),
    pre-stroked text (no text entity), settings defaults, the parser's
    error-vs-warning contract, and file naming incl. repetitive-family
    stems with counts. README links it.
2026-07-04 CONTRIBUTING.md: contribute without the hardware
    Dev setup with the simulation fallback (pigpio absent = full web UI on
    any machine), the TSJ_SPEC lockstep rule, keep-simulation-working and
    phone-first ground rules; flags a tsj_parser pytest harness as a good
    first contribution.
2026-07-04 HARDWARE.md: sled build guide draft v0.1 + model file fixes
    Print manifest mapped from 3dmodels/ (stl = print truth, f3d/f3z =
    Fusion source), Robert's BOM v0.1 (frame / motion / electronics /
    power / laser / fasteners with status columns), photo-led assembly
    skeleton with capture specs, wiring section stubbed with the
    DLC32-vs-direct-GPIO reconciliation note, laser safety. Renamed the
    "Ganrty" typo STL and the DLC23 bracket files to DLC32 (the board is
    an MKS DLC32 V2.1). README links the guide.
    [Gantry to Frame Bracket.stl, MKS DLC32 Bracket.stl]
2026-07-04 HARDWARE.md: Frame.f3d is the sled assembly file; laser is 1.6 W
    Frame.f3d moved out of the print manifest -- it's the whole-machine
    Fusion assembly, no STL. Synced the 1.6 W laser wattage through the
    BOM and safety sections (intro was already corrected); gantry bracket
    quantities now 2.
2026-07-04 Belt tensioner: 3-piece printed design + manifest/BOM update
    Tensioner.f3z source + Tensioner_Body1-3 STLs. Off the to-be-designed
    list; BOM motion row now reads printed.
    [Tensioner.f3z, Tensioner_Body1.stl, Tensioner_Body2.stl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]
2026-07-04 HARDWARE.md: limit switch placement -- 2 gantry, 2 bridge supports
    All four switches live on existing prints (gantry brackets + the two
    bridge supports), so the separate switch-mount design item is gone.
2026-07-04 HARDWARE.md: MKS DLC32 Bracket IS the controller mount
    Off the to-be-designed list; the electronics BOM row now points at the
    printed bracket.
2026-07-04 HARDWARE.md: motor pulleys are 20T, 6 mm bore
2026-07-04 HARDWARE.md: idlers are smooth (non-toothed); motor pulley qty 1
2026-07-04 HARDWARE.md: idlers are toothed; drop duplicated row
2026-07-04 HARDWARE.md: belt is open GT2 cut to the timber length; idlers 1T+2S
    Belt length isn't a fixed spec -- it's cut to suit the timber being
    scribed. Idler split per Robert: 1 toothed + 2 smooth.
2026-07-04 HARDWARE.md: V-rollers are uxcell nylon w/ 686Z bearings + 5.9 mm axles
    6 mm bearing bore, 5.9 mm rod for slip fit.
2026-07-04 HARDWARE.md: gantry is a prebuilt V-Slot NEMA17 belt actuator
    eBay bundle, stock tensioner swapped for the printed 3-piece one;
    assembly step 3 updated to match.
2026-07-04 HARDWARE.md: drop rows supplied by the gantry bundle
    The NEMA17 stepper and the 20x20x500 rail come with the prebuilt
    actuator; motion + frame BOM sections are now fully specified.
2026-07-05 Reconcile motion architecture: Pi server streams g-code to a GRBL controller
    The pigpio direct-GPIO drive in the repo was speculative scaffolding that
    never matched the bench hardware (which was a 3018 Woodpecker GRBL board +
    Pi 5 server; the MKS DLC32 V2.1 supersedes the Woodpecker).
    - hardware/executor.py: rewrite as a GRBL g-code sender skeleton over USB
    serial — real connect/handshake/call-response plumbing and M3/M5 laser
    control; entity->g-code motion mapping stays TODO. HAS_HARDWARE now
    enumerates ports at import instead of opening anything.
    - app/executor.py: gate on HAS_HARDWARE. Fixes the dead simulation
    fallback — the old except-ImportError never fired, so dev-machine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
    [executor.py]
2026-07-18 WiFi transport: drop the Pi - stream g-code to the DLC32 v2.2 over TCP
    The MKS DLC32 v2.2 (FluidNC) hosts its own hotspot and takes raw g-code
    on TCP port 23, so the Raspberry Pi comes off the sled; any laptop on
    the sled's WiFi runs this server. USB serial remains a bench fallback
    (GRBL_TRANSPORT = "serial").
    - hardware/executor.py: _TcpLink/_SerialLink behind one link surface;
    hardware_available() probes per burn (no restart-after-plug-in wart)
    - app/executor.py: simulated completions now say SIMULATED - over WiFi,
    "unreachable" can mean the hotspot dropped, and that must never read
    as a successful burn
    - config.py: GRBL_TRANSPORT / GRBL_HOST / GRBL_TCP_PORT / GRBL_AP_SSID;
    serial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
    [executor.py]
2026-07-18 DLC32 bench bring-up: FluidNC v4.0.3 configured, verified, config in repo
    The board (flashed with FluidNC v4.0.3 via the web installer) now runs
    hardware/fluidnc/config.yaml - base: official MKS_DLC32_v21_laser.yaml,
    renamed TimberScribe Sled / V2.2, laser speed_map already 0..1000. The
    donor Z axis is REMOVED: its limit input (gpio.34, active-high, no
    internal pulls) floated high unwired and threw a phantom hard-limit
    alarm on every boot; the sled is two-axis with a fixed-focus laser.
    Verified on the bench over USB: clean boot (no ALARM), AP "FluidNC" at
    192.168.0.1, telnet on port 23, TimberScribe preamble G20/G90/M5 all
    acknowledged, status Idle.
    hardware/fluidnc/upload_config.py is the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
    [config.yaml]
2026-07-18 Move sled AP to 192.168.4.1 - the FluidNC default collided with the LAN
    The shop router is 192.168.0.1, the exact FluidNC AP default, so the
    laptop could never hold both networks. Set $AP/IP=192.168.4.1 on the
    board (NVS setting - stored on the controller, NOT in config.yaml;
    noted in HARDWARE.md 4.1), verified in the boot log after restart.
    config.py GRBL_HOST updated to match.
2026-07-18 Configure homing: Y to datum edge (cycle 1), X to anchor end (cycle 2)
    Homing now matches the .tsj coordinate frame: gantry homes to the
    fixed-roller (datum) edge, then the bridge homes to the anchor
    (tape-hook) end; each axis zeroes at its switch plus 2 mm pulloff.
    Seek/feed detuned (2000/300 mm/min) for first tests. Uploaded to the
    board, boots clean. Wiring scheme documented in HARDWARE.md 4: one NO
    switch per axis at the homing end into the X-/Y- headers; series-NC
    both-ends wiring stays a documented later option.
    [config.yaml]
2026-07-18 HARDWARE.md: limit switches are 3-wire 5V modules; endstop header facts
    Board endstop headers are 5V/GND/S per manual IX; note the pin-marking
    check before power and the manual 5V-LED short warning.
2026-07-18 HARDWARE.md: 12V-labeled limit switches verified working at 5V
    Both endstop modules (IN/GND/12V) respond correctly from the header 5V
    supply - Pn:X/Pn:Y flags toggle, polarity matches the config.
2026-07-18 BOM: DLC32 needs plug-in stepper driver sticks (found via dead motors)
    Homing stepped in firmware (MPos moved) with silent motors; the DLC32
    driver sockets are plug-in (manual VI) unlike the Woodpecker
    predecessor with onboard drivers. Two sticks needed, 1/16 microstep
    jumpers, Vref to set, no hot-plugging.
2026-07-20 HARDWARE.md: TMC2209 DIP settings + socket orientation from manual figures
    DIP per socket: 1 ON, 2 ON, 3 down = 1/16 for TMC2209 (M0/M1/M2,
    up=High; 2209 ignores position 3). Orientation: EN->EN top of green
    column, DIR->DIR bottom; VM tops the right column. Vref rule of thumb
    recorded.
2026-07-20 Implement entity -> g-code emitters: the burn pipeline is complete
    .tsj entities now translate to real motion, streamed line-by-line:
    - line/polyline: laser-off travel to start, M4, chained G1s at scribe
    feed (closed polylines return to the first point), M5
    - circle (peg bores): center cross first - the framer drills to it -
    then the outline as a full-circle G3
    - arc: always G3 - .tsj arcs sweep in the increasing-angle direction
    of P(theta) = C + r(cos,sin), which is g-code CCW (verified against
    the writer, ScribeTsj.cs/ScribeSolprof.cs)
    Design choices: travels are laser-off G1s at the .tsj travel feed (not
    G0 - rapids run at the uncalibrated max_rate and the travel profile is
    the o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
    [executor.py]
2026-07-21 Two-mode architecture: shop server (Pi-ready) + SD-card field mode
    Shop mode: sled joins the LAN (FluidNC STA), the server runs on a
    plugged-in Pi or laptop, phone drives the UI; GRBL_HOST is now
    fluidnc.local (mDNS - resolves on both the LAN and the sled hotspot).
    Field mode: out of range the sled auto-falls-back to its hotspot and
    burns run serverless from the SD card.
    - hardware/executor.py: emitters now write to a pluggable sink;
    gcode_program() renders the identical line-for-line program for
    export. burn() only force-M5s on the error path, so a clean stream
    and an exported file are byte-identical.
    - Export surfaces: "Export .gcode" button on the face page
    (/job/<id>/gcode, uses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
    [executor.py]
